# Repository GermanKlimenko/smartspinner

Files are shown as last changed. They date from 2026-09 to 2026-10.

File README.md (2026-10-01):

# Умный спиннер для трейдера

Проект **Смартлаба**. Выбранные визуальные направления: [«Пульс рынка»](public/assets/smartlab/market-full.png) и [«Биржевой сигнал»](public/assets/smartlab/signals-full.png). [Галерея на сайте](https://germanklimenko.github.io/smartspinner/#smartlab).

Это концептуальные изображения с демонстрационными котировками, не фотографии работающего прототипа. Свечной вариант не выбран и на сайте не размещён.

[Сайт проекта](https://germanklimenko.github.io/smartspinner/) · [Фото реального POV-вентилятора](public/assets/reference-fan/README.md)

## Текущий этап: неподвижный стенд B0.1

Документация для опытной ручной сборки подготовлена. **На железе не проверено.**
Цель конечного устройства: четыре луча, Ø100 мм, по 20 верхних и 12 торцевых RGB. Это целевые параметры, не характеристики испытанного образца.

- [Полный пакет стенда ZIP](bench/SmartSpinner_B01_DIY_Package.zip)
- [Инструкция PDF](bench/v0.1/output/pdf/SmartSpinner_B01_Bench.pdf)
- [Список покупок](bench/v0.1/shopping.md)
- [Исходники, схема соединений и прошивка](bench/v0.1/)
- [Результаты программных проверок](bench/v0.1/build/verification.txt)
- [Аудит электроники от 29.09.2026](audits/2026-09-29-electronics/README.md)

B0.1: UNO R3, 6 драйверов SM16306SJ, 32 выводных RGB LED, 96 каналов. Неподвижный опыт без аккумулятора и мотора. Не закреплять стенд на купленном голографическом вентиляторе.

## Старые версии сняты

**STOP FABRICATION. Прежние электрические файлы v0.4/v0.5 нельзя использовать для изготовления и подключения аккумулятора.**

Удалены из текущего каталога устаревшие версии v0.1/v0.2, электрические пакеты v0.4/v0.5 и прежние материалы с завышенной оценкой готовности. Они восстановимы из истории Git. Аудит относится к историческому коммиту [1635129](https://github.com/GermanKlimenko/smartspinner/tree/1635129707aff4e6b09a5e4b1feb32eedf14c7ca), поэтому его пути и контрольные суммы описывают именно тот снимок.

Сохранена параметрическая геометрия v0.3 как основа для переработки, а не согласованная с электроникой сборка. Визуализации — концептуальные рендеры, не фотографии работающего прототипа.

## Следующие шаги

1. Купить компоненты по списку B0.1 и собрать неподвижный стенд.
2. Проверить адресацию, токи, отключение, нагрев и оптические импульсы; заполнить протокол.
3. По результатам разработать новую компактную схему и PCB, согласовать с корпусом.
4. После ERC/DRC, DFM и проверки питания подготовить заказ 10 PCBA.

## Локальный запуск сайта

Node.js >= 22.13, pnpm. Команды: `pnpm install --frozen-lockfile`, `pnpm dev`, `pnpm build`.
Публикация — GitHub Pages через workflow в `.github/workflows/pages.yml`.

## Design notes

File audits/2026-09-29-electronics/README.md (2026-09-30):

# SmartSpinner — ревизия электроники с нуля

Примечание к публикации 30.09.2026: старые схемы и пакеты сняты из текущего каталога. Все пути и выводы ниже относятся к историческому коммиту [1635129](https://github.com/GermanKlimenko/smartspinner/tree/1635129707aff4e6b09a5e4b1feb32eedf14c7ca). Для повторного запуска аудита восстановите этот снимок в отдельной рабочей копии; не используйте его для изготовления.

Дата: 29 сентября 2026. Проверяемая база: Git `1635129`, схема v0.5, плата v0.4, механика v0.3. Это отчёт о проверке, **не исправленный производственный релиз**.

## Краткий вердикт

**STOP FABRICATION: по существующим файлам заказывать изготовление и монтаж нельзя. Подключать аккумулятор к собранной по ним плате нельзя.**

Проект содержит пригодную для обсуждения концепцию, но не согласованный комплект рабочего устройства. Обнаружены ошибки соединений питания, непригодные посадочные места, расхождение схемы с платой и платы с корпусом. Ранее данная оценка готовности была завышена: это не ситуация «разводчику осталось проверить несколько мелочей».

Сама идея четырёхлучевого POV-спиннера не опровергнута. Предварительно можно сохранить nRF52840/BLE и целевые 4 × 20 верхних + 4 × 12 торцевых RGB-пикселей. Но выбор LED, питание, фазовая синхронизация и размещение требуют новой проверки. Партнёрские картинки не являются доказательством достижимой чёткости.

### Что действительно проверено

- Прочитаны генераторы, исходные KiCad, BOM/CPL, файлы производства и механики.
- KiCad 10.0.6 заново экспортировал электрический netlist; заново выполнены ERC и DRC обеих плат.
- Соединения и посадочные места сопоставлены с документацией компонентов.
- Пересчитаны временной бюджет POV, пределы датчиков и сценарии энергопотребления.
- Контур PCB совмещён с действующими STEP-моделями, посчитаны пересечения твёрдых тел.

Не было изготовленного образца, осциллограмм, оптического теста, измерений температуры, тока, времени работы и радиосвязи. Проверка файлов не заменяет эти испытания. Дубликаты файлов с суффиксом « 2» не принимались за новую ревизию. Исходные проектные файлы не изменялись; контрольные суммы сохранены.

## 1. Подтверждённые блокирующие ошибки

### E01 · P0 · Генератор схемы перепутал физические выводы и сети

В `tools/generate_schematic_v0_5.py:88–92` локальные координаты выводов символа создаются с положительной осью Y вверх; в строке 158 метки соединений ставятся на листе без необходимого переворота Y. Поэтому порядок сетей на каждой стороне многовыводного символа развёрнут. Это не предположение по картинке: результат подтверждён экспортом KiCad.

| Компонент и физический вывод | Фактическая сеть в v0.5 | Требуемая функция |
|---|---|---|
| U5 MCP73831, 4 VDD | GND | Вход зарядки 5 В |
| U5, 2 VSS | CHG_5V | Земля |
| U5, 3 VBAT | CHG_STAT | Аккумулятор |
| U3 TPS61023, 3 VIN | GND | Аккумулятор |
| U3, 4 GND | VBAT | Земля |
| U3, 5 SW / 6 VOUT | 5V_RAW / BOOST_SW | BOOST_SW / 5V_RAW |
| U4 LDO, 1 IN / 2 GND | GND / VBAT | VBAT / GND |
| U4, 5 OUT | Не подключён | 3V3 |
| U1, 51 SWDIO / 53 SWDCLK | 3V3 / 3V3 | Интерфейс программирования |
| U1, 28 VDD / 30 VDDH | SWDCLK / SWDIO | Питание модуля |

Полный список: [schematic-connectivity.json](schematic-connectivity.json), исходный экспорт: [schematic.net.xml](schematic.net.xml). Та же ошибка затрагивает разъёмы и сигнальные цепи. Исправить одну надпись недостаточно: необходимо проверить соответствие каждого вывода каждой сети после регенерации.

Распиновки сверены с [Microchip MCP73831](https://ww1.microchip.com/downloads/en/DeviceDoc/20001984g.pdf), [TI TPS61023](https://www.ti.com/lit/ds/symlink/tps61023.pdf), [TI TPS7A20](https://www.ti.com/lit/ds/symlink/tps7a20.pdf) и [Raytac MDBT50Q](https://www.raytac.com/tw/download/index.php?index_id=24).

### E02 · P0 · «Нет ошибок ERC» здесь не означает исправную схему

В генераторе **все выводы объявлены `passive`**. ERC не получает нормального описания входов питания, выходов, открытых стоков и т. п. Перепутанное питание поэтому не выявляется привычными проверками типов выводов.

Новый прогон дал 89 предупреждений, 0 ошибок категории error. Но E01 остаётся реальной электрической ошибкой. Нужно заменить условные символы проверенными, назначить корректные типы выводов, обработать питание, NC и исключения, затем повторить ERC и ручную проверку netlist. Файл `.kicad_pro` с полноценными настройками проекта в проверяемом комплекте отсутствует.

### E03 · P0 · Неверно рассчитано напряжение повышающего преобразователя

Генератор задаёт R2 = 910 кОм и R3 = 100 кОм и утверждает, что опорное напряжение TPS61023 равно 0,5 В. По таблице electrical characteristics оно типично **0,595 В в PWM**, 0,601 В в PFM.

Расчёт задуманной цепи: `Vout = 0,595 × (1 + 910/100) = 6,0095 В`.

Это выше допустимого диапазона настройки выхода 5,5 В. Защита от перенапряжения вмешается; **расчёт не означает, что реально получится стабильный выход 6 В**. Даже после исправления E01 этот узел останется неправильным. Нужны новый делитель, расчёт допусков и проверка преобразователя с реальной нагрузкой. Источник: [TI TPS61023, таблица 6.5 и типовая схема](https://www.ti.com/lit/ds/symlink/tps61023.pdf).

### E04 · P0 · Посадочные места на PCB — условные заменители реальных корпусов

| Позиция | Площадок в v0.4 PCB | Выводов у указанного компонента |
|---|---:|---:|
| U1 MDBT50Q | 15 | 61 |
| U2, U9 74AHCT125 | 6 на корпус | 14 |
| U3 TPS61023 | 3 | 6 |
| U4 TPS7A20 | 3 | 5 |
| U5 MCP73831 | 3 | 5 |
| U7 BMI270 | 4 | 14 |
| U8 TPS22918 | 3 | 6 |

Это не просто отсутствие 3D-моделей. На эти площадки нельзя установить указанные детали с правильными соединениями. В v0.4 преобразователи изображены как трёхконтактные блоки; входы и выходы логических буферов не представлены как полноценная схема. Инвентаризация: [pcb-inventory.json](pcb-inventory.json).

### E05 · P0 · Схема, BOM и PCB не являются одним согласованным проектом

В схеме 40 символов; 31 без назначенного footprint, включая условные блоки цепочек LED. Все 128 светодиодов не развёрнуты в индивидуальные компоненты. В основной PCB 104 footprint; в одной торцевой 13, а таких торцевых плат предполагается четыре.

L1 и RPROG из BOM не найдены как компоненты основной PCB. Обратная связь и большая часть обвязки в PCB отсутствуют. Нумерация также изменилась: C1–C4 на плате v0.4 — четыре накопительных конденсатора лучей, в схеме v0.5 это другие конденсаторы зарядки и LDO. Нет основания использовать старые BOM/CPL для новой схемы.

Нужны единый проект, одна библиотека, уникальные позиционные обозначения и проверка `schematic ↔ PCB ↔ BOM ↔ CPL`. Экспорт Gerber из существующей геометрии этого не исправляет.

### E06 · P0 · Разводка не завершена, производственный пакет неполон

Свежий DRC основной платы: **68 неподключённых элементов**, плюс 50 прочих нарушений; торцевой: **4 неподключённых**, плюс 7 прочих. Это категории отчёта, не число уникальных цепей. См. [main-drc.json](main-drc.json), [tip-drc.json](tip-drc.json).

В опубликованном каталоге Gerber отсутствуют файлы паяльной маски и пасты для обеих сторон. См. [fabrication-files.json](fabrication-files.json). Наличие файлов меди и сверловки не делает пакет готовым для PCBA.

В основной PCB нет полигонов земли; внутренние слои заявлены, но полноценная структура возвратных токов не реализована. Графический прямоугольник RF keep-out не является запретной зоной для меди всех слоёв. Отверстия переходов 0,15 мм на основной и 0,10 мм на торцевой плате поставлены непосредственно в площадки LED. Это требует отдельного согласования технологии, заполнения/закрытия via-in-pad либо изменения разводки. Очень мягкие DRC-ограничения сами по себе не доказывают производимость.

### E07 · P0 · Корпус и плата физически несовместимы

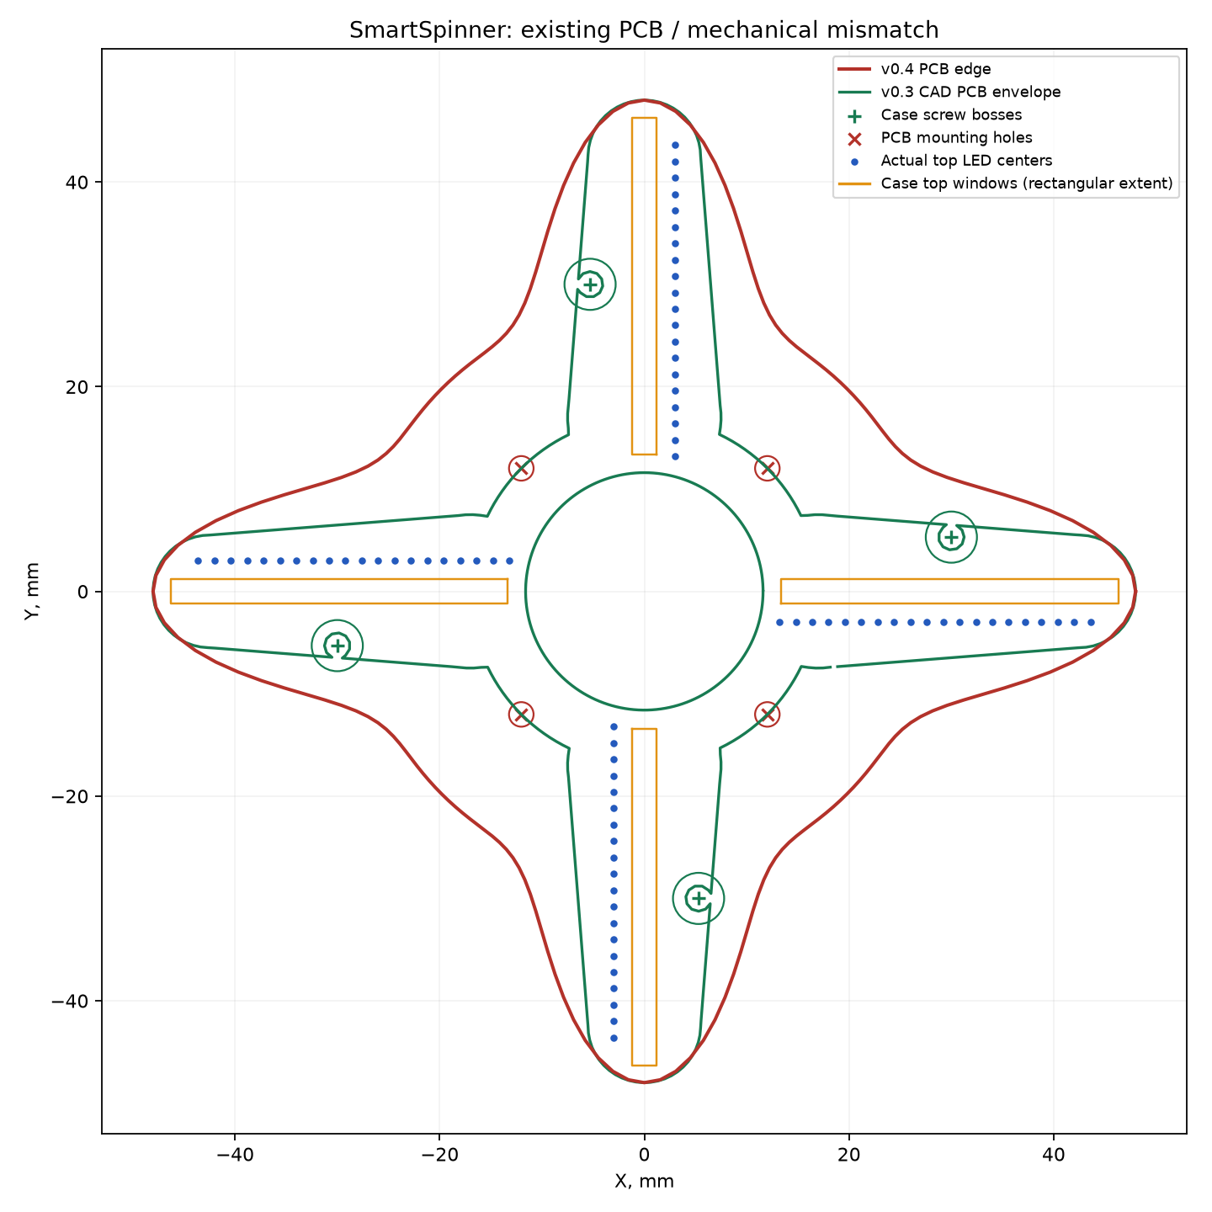
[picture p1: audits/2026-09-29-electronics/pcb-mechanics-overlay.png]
Совмещение актуальной платы и механики


Красный контур — PCB v0.4; зелёный — посадочный габарит PCB в механике v0.3; синие точки — LED; оранжевые полосы — окна.

- Отверстия PCB стоят около радиуса 17 мм по диагоналям. В корпусе крепёж расположен около точек `(30; 5,3)` мм и их поворотов на 90°. Они не совпадают.
- Лучи PCB существенно шире полостей корпуса. При положении платы Z = 6,5…7,5 мм объём пересечения PCB с нижней частью корпуса составляет около **625 мм³**.
- Даже предусмотренный в v0.3 STEP-габарит платы пересекается с нижней частью корпуса: около **216 мм³**. Поэтому нельзя считать и прежнюю механику полностью проверенной.
- Ряд верхних LED смещён поперёк луча на 3 мм, тогда как полуширина окна 1,2 мм. Ряд не попадает в предусмотренное окно.
- Первый LED начинается с 13,2 мм вместо 14,8 мм; шаг торцевых LED 1,10 мм против 1,05 мм в механике. На 12 позициях разница длины ряда 0,55 мм.
- Проверяемая механика имеет толщину 16 мм, а не первоначальные 12–14 мм. Между верхними LED и рассеивателем есть большой зазор; резкость и паразитная засветка не проверены.

Расчёт выполнен на настоящих STEP-телах, не на иллюстрации. Преобразование координат и допущения сохранены в [mechanical-comparison.json](mechanical-comparison.json). Нужны общие параметры механики и платы, компонентные 3D-модели, проверка всех зазоров и сборки.

## 2. Компоненты, питание и безопасный запуск

### E08 · P0 · MPN датчика Hall не соответствует выбранному корпусу

Указанный **DRV5033AJQLPGM** — вариант TO-92/LPG; в схеме ему назначен SOT-23, а в BOM встречается другой тип корпуса. Более того, назначение выводов 2/3 у LPG и SOT-23/DBZ различается. Нельзя просто заменить рисунок footprint без проверки MPN и pin map. [TI: именно DRV5033AJQLPGM](https://www.ti.com/product/es-mx/DRV5033/part-details/DRV5033AJQLPGM), [распиновки](https://www.ti.com/lit/ds/symlink/drv5033.pdf).

### E09 · P0 · Распиновки LED не подтверждены для заказываемой модификации

На PCB оба типа LED используют `1=VDD, 2=DOUT, 3=GND, 4=DIN`. Документ OPSCO для EC10 показывает `1=GND, 2=DIN, 3=VDD, 4=DOUT`; документ Normand для EC15 — `1=DIN, 2=VDD, 3=DOUT, 4=GND`.

Нумерация и ориентация должны быть согласованы с **конкретным производителем и ревизией**. Для EC10 поворот корпуса может объяснять часть пространственного соответствия, но не доказывает правильность нумерации, CPL и сборочной ориентации. Документ EC15 от Normand не является подтверждением всех вариантов OPSCO. До выбора закупаемой позиции обе посадки остаются неподтверждёнными. Нужны land pattern, pin-1, ориентация ленты и контрольный монтаж.

Источники: [OPSCO EC10 REV.01](https://cdn-shop.adafruit.com/product-files/5849/SK6805-EC10-000_REV.01_EN.pdf), [Normand EC15 REV.05](https://www.normandled.com/upload/202003/SK6805-EC15%20LED%20Datasheet.pdf).

### E10 · P1 · Зарядка и совместимость уровней

Даже по задуманным, ещё не перепутанным соединениям STAT у MCP73831 напрямую идёт в GPIO nRF. Этот выход может выдавать высокий уровень от входного питания зарядки, то есть около 5 В. Для 3,3-вольтового GPIO нужен согласователь либо подходящий вариант выхода с открытым стоком и подтяжкой к 3,3 В.

RPROG = 10 кОм задаёт около 100 мА; это не 150 мА, фигурировавшие в BOM. Для условных 500 мА·ч одна только идеальная зарядка током 100 мА заняла бы 5 часов, реальная с фазой CV — дольше. Отдельного power-path нет: потребление устройства от батарейного узла может нарушать определение окончания зарядки. Следует аппаратно исключить работу LED на зарядке либо спроектировать корректное разделение питания. [Microchip MCP73831/2](https://ww1.microchip.com/downloads/en/DeviceDoc/20001984g.pdf).

Зарядник не заменяет защиту аккумулятора от КЗ/переразряда. Нужны точная модель пакета, допустимые токи, защитная плата и температурные условия зарядки. Две симметричные ячейки нельзя считать согласованным 1S2P-пакетом без определения их соединения, одинаковости и защиты. Полости в корпусе не доказывают существование подходящего аккумулятора на 500 мА·ч.

### E11 · P1 · Питание требует полного пересчёта и проверки переходных процессов

- «3,7 A» у TPS61023 — предел тока ключа, а не гарантированные 3,7 A на выходе 5 В. Нужен расчёт при минимальном напряжении батареи, с потерями, нагревом и насыщением дросселя.
- [TPS22918](https://www.ti.com/lit/ds/symlink/tps22918.pdf) рассчитан на ток до 2 A при оговорённых условиях, но не является программируемым ограничителем тока. Один только предел яркости в прошивке не защищает от её сбоя или всех переходных нагрузок.
- На LED_EN нет гарантированного выключенного состояния внешним резистором. Нужно определить запуск, сброс MCU, отключение и последовательность шин. ON нельзя оставлять плавающим. Неподключённый QOD сам по себе допустим и не является доказанной ошибкой.
- 3,3-вольтовый LDO от Li-ion перестаёт стабилизировать 3,3 В в нижней части разряда. Это не обязательно останавливает MCU, но требует проверки минимального питания всех узлов и порога отключения. [TPS7A20](https://www.ti.com/lit/ds/symlink/tps7a20.pdf).
- Недостаточно локальной развязки у контроллера, буферов, Hall и цепей LED. Требуется расчёт эффективной ёмкости с DC-bias, токов по лучам, провалов питания, возвратных путей и помех BLE.
- Режим «LED показывают чёрный» и режим «питание LED выключено» имеют разное потребление. Для ожидания нужно физическое отключение световой части.

### E12 · P1 · Буферы, GPIO, программирование и RF

74AHCT125 — подходящий класс согласования 3,3 → 5 В при правильном подключении: AHCT питается от 4,5–5,5 В и имеет TTL-порог входа. В старой PCB буферы сидят на 3V3 и не реализуют нужное преобразование. Входы актуального Nexperia имеют overvoltage tolerance; поэтому утверждать неизбежную обратную подпитку именно через их входную защиту нельзя. Всё равно необходимо проверить поведение выключенных шин и выходов. [Nexperia 74AHC/AHCT125](https://assets.nexperia.com/documents/data-sheet/74AHC_AHCT125.pdf).

Задуманное назначение P0.03/P0.09/P0.10 под высокочастотные LED-данные не учитывает RF-рекомендации модуля: эти выводы имеют ограничения при активном радио. Нужен новый GPIO-план, проверка NFC-конфигурации, режима питания модуля, неиспользуемых выводов и физического keep-out антенны. [Raytac MDBT50Q](https://www.raytac.com/tw/download/index.php?index_id=24).

SWD-разъём не согласован: пять выводов в схеме, четыре площадки на PCB, шестиконтактный интерфейс в BOM. Для варианта TC2030-CTX контакт 3 — reset, 4 — clock; задуманная схема меняет их местами. Нужно выбрать конкретный кабель и посадку, обеспечить доступ при сборке. [Tag-Connect TC2030-CTX](https://www.tag-connect.com/product/tc2030-ctx-etm).

## 3. Сможет ли это показывать картинку

### E13 · P1 · Четыре луча не устраняют ограничения LED

Проверяемая гипотеза: восемь независимых цепочек — четыре по 20 LED сверху и четыре по 12 LED на торце, передача 800 кбит/с, 24 бита на RGB, reset более 80 мкс. Нижние границы времени обновления — около 680 и 440 мкс соответственно. Это оптимистичный предел без затрат прошивки, а не измеренная производительность.

| Скорость, об/мин | Проходов 4 лучей в секунду | Обновлений за оборот одной верхней цепочки, не более | Торцевой, не более |
|---:|---:|---:|---:|
| 300 | 20 | 294 | 454 |
| 600 | 40 | 147 | 227 |
| 900 | 60 | 98 | 151 |
| 1200 | 80 | 73 | 113 |

При 900 об/мин за 680 мкс точка на радиусе 50 мм перемещается примерно на 3,20 мм. У реального крайнего верхнего LED радиус меньше, поэтому линейное перемещение немного меньше. Это ограничивает угловую детализацию. Четыре луча увеличивают повторяемость изображения; нельзя одновременно считать их безусловным четырёхкратным приростом и частоты, и углового разрешения.

Отдельный предел — внутренний PWM светодиода. В проверенных документах встречаются 1,2 кГц для EC15 и 4 кГц для EC10; другие ревизии могут отличаться. PWM не синхронизирован с вращением, поэтому нужно проверить оптическую задержку, полосы и разрывы на малой яркости. Нельзя выводить качество изображения только из скорости передачи данных.

**Вывод:** выбранные LED не доказаны как подходящие для обещанной чёткой графики. Это не доказательство невозможности POV. До окончательной разводки нужен оптический стенд с реальными закупаемыми LED и измерением света фотодиодом. Если результата нет — переход на проверенное быстрое тактируемое решение или RGB-драйверы с управляемыми latch/OE. Конкретный заменяющий компонент пока не выбран; его геометрия и токи тоже потребуют расчёта.

20 LED по лучу дают 20 радиальных отсчётов, не квадрат 20 × 20. Центральная область остаётся без изображения из-за подшипника и пальцев. Полярный рендеринг должен учитывать реальные координаты каждого LED, а не только радиус.

### E14 · P1 · nRF52840 предварительно пригоден, доказательной прошивки нет

У nRF52840 есть четыре PWM-блока по четыре канала с EasyDMA. Поэтому восемь параллельных потоков технически возможны; отдельный GPIO на каждый из 128 LED не нужен. Но требуется реализовать и измерить генерацию восьми потоков, фазовую синхронизацию и работу одновременно с BLE. В проверяемом проекте рабочая прошивка этого не обнаружена. [Nordic: возможности nRF52840](https://docs.nordicsemi.com/r/bundle/ps_nrf52840/page/keyfeatures_html5.html).

Нужны обработчик Hall с аппаратными timestamp, планировщик угла, корректировка изменения периода, буферы полярного изображения, watchdog, контроль батареи и аппаратно безопасное гашение при остановке/сбросе. Bluetooth должен передавать содержимое, не задавать точные моменты включения LED.

### E15 · P1 · BMI270 не подходит для заявленной роли измерителя скорости вращения

Максимальный диапазон гироскопа ±2000°/с соответствует около **333 об/мин**. При 600 об/мин уже 3600°/с, при 900 — 5400°/с. Он будет насыщаться, поэтому не может гарантированно компенсировать скорость и фазу в этом диапазоне.

При радиусе 14 мм и 1200 об/мин центростремительное ускорение около 22,5g, выше диапазона акселерометра ±16g. IMU можно оставить для других задач после пересмотра роли, но не обещать на его основе стабилизацию изображения. [Bosch BMI270](https://www.bosch-sensortec.com/en/products/motion-sensors/imus/bmi270).

### E16 · P1 · Hall, магнит и дрожание руки

В механике **есть** карман магнита в неподвижной относительно пальцев крышке — неверно было бы объявлять магнит полностью забытым. Но модель, ориентация и поле магнита не заданы в BOM; положение Hall на PCB не совпадает с механической разметкой. Работу рядом со стальным подшипником, допуски зазора и стабильность импульса никто не измерял.

Одна метка за оборот даёт период и индекс, но не непрерывный угол между импульсами. Она не измеряет направление без дополнительных предположений. Если крышка поворачивается в пальцах, вместе с ней меняется опорное направление картинки. Дрожание оси также не исправляется одной меткой.

Для первой версии рационально разделить: синхронизацию относительно крышки, оценку изменения скорости и отдельно устойчивость изображения в руке. Жёсткий стенд нужен для измерений и отладки; из этого не следует, что устройство сможет работать только на подставке. Финальное доказательство удобства и чёткости — тест в руке, а не рендер.

## 4. Энергия: новый расчёт вместо обещания автономности

128 RGB-пикселей — это до 384 цветовых каналов. При условных 5 мА на канал полный белый требует **1,92 A при 5 В только на свечение**, ещё до собственного потребления микросхем LED. «5 мА на пиксель» не равно «5 мА на каждый цвет».

Следующая таблица — **сценарная чувствительность, не спецификация батареи и не прогноз измеренной автономности**. Приняты условные 0,5 мА собственного тока каждого LED, 5 мА на цветовой канал, КПД boost 85%, батарея 3,7 В / 500 мА·ч, используемая ёмкость 85%, прочая электроника 15 мА от батареи. Токи конкретных ревизий LED и реальная ёмкость подходящего пакета пока не подтверждены.

| Средняя загрузка цветовых каналов | Ток LED по 5 В | Ток батареи | Расчётное время |
|---:|---:|---:|---:|
| 0%, питание LED включено | 64 мА | 117 мА | 218 мин |
| 10% | 256 мА | 422 мА | 60 мин |
| 25% | 544 мА | 880 мА | 29 мин |
| 35% | 736 мА | 1185 мА | 22 мин |
| 100%, полный белый | 1984 мА | 3169 мА | 8 мин — математически, режим не разрешён |

«Загрузка» учитывает одновременно долю светящихся точек, яркость и количество активных цветов. Это не просто положение ползунка яркости. Редкий зелёный текст и сплошной белый диск дают совершенно разные результаты. При низком напряжении батареи входной ток ещё выше. Возможности маленького аккумулятора, защита и нагрев могут исключить режим задолго до расчётного исчерпания ёмкости.

Ограничение яркости снижает средний ток, но не обязательно амплитуду импульсов PWM. Проверять нужно среднюю и пиковую нагрузку, ёмкости и провалы питания. Пока корректный ответ об автономности: **не установлена**. Все формулы и допущения: [calculations.json](calculations.json).

## 5. Предлагаемая архитектура следующей ревизии

Сохранить целевой форм-фактор и BLE как требования, но не копировать нынешнюю разводку. Рекомендуемый порядок решений:

1. **Оптика до финальной PCB.** Один луч 20 LED и один торец 12 LED, настоящий световой тест в диапазоне 300–1200 об/мин. Диапазон — испытательный, а не утверждение о типичной скорости в руках. Выбрать допустимое качество текста, мерцание, яркость и минимальные рабочие обороты.
2. **Согласовать аккумулятор и питание.** Выбрать физически существующий защищённый пакет, токовый бюджет, зарядку, режим на доке и аппаратное выключение LED. После этого выбирать преобразователь и ограничение нагрузки.
3. **Собрать полную принципиальную схему заново.** Реальные символы, все светодиоды и обвязка, разъёмы, измерительные точки, программирование, режимы включения/выключения. Добавить автоматические проверки критических pin-to-net соединений, чтобы ошибка генератора не повторилась.
4. **Совместно переработать размещение и корпус.** Единый DXF/параметры, допустимые зоны компонентов, световые окна, высоты, антенна, магниты, батарея, крепёж и балансировка по реальным массам. Четыре одинаковых луча сами по себе баланс не гарантируют. Торцевые платы должны фиксироваться корпусом; пайка не должна воспринимать удар раскрутки.
5. **Развести согласованную плату.** Проверенные footprints из документации поставщиков, питание/земля/RF, технологические ограничения выбранного производства. Устранить все неподключения, разрешить каждое исключение ERC/DRC, сравнить netlist.
6. **Первый экземпляр и испытания.** Лабораторный источник с ограничением тока до аккумулятора; проверка шин, зарядки, запуска, LED, Hall, BLE и температуры. Затем безопасный тест вращения в защитном ограждении и тест в руке. Лишь после этого — партия 10 устройств.

### Критерии готовности к заказу

- Одна версия KiCad: `.kicad_pro`, `.kicad_sch`, `.kicad_pcb`, локальные библиотеки и 3D-модели.
- PDF полной схемы, BOM с точными MPN и допустимыми заменами, CPL, сборочные чертежи с pin-1 и ориентацией.
- Gerber меди, маски, пасты, шелкографии и контура; сверловка, стек слоёв, требования via-in-pad и панелизации.
- Разъёмы и четыре торцевых модуля согласованы по числу, нумерации, стороне и монтажу.
- ERC/DRC и сверка схемы с платой без необъяснённых нарушений; независимая проверка питания и распиновок; DFM от изготовителя.
- Расчёты питания, токов, нагрева и световых таймингов; согласованная батарея и механика.
- Прошивка для проверки, инструкция первого включения и критерии приёмки.

Отдельный критерий после изготовления: реальная чёткость POV, автономность, нагрев, безопасность батареи и прочность подтверждены измерениями. Даже идеальные файлы не дают этого доказательства заранее.

## 6. Что это означает для переговоров с разработчиком

Нужен заказ **на разработку и проверку электроники прототипа**, а не только на трассировку готовой схемы. Изготовитель PCBA может выпустить и собрать платы по согласованным файлам, но не обязан бесплатно доводить принцип работы и исправлять архитектуру.

Техническое возражение, что имеющейся схемы недостаточно, подтверждается аудитом. При этом аудит не проверяет коммерческую оценку Азата и не позволяет обещать конкретное число часов экономии. Будущему исполнителю стоит передать этот отчёт и исходники как материал для ревизии, прямо исключив использование старых Gerber для заказа.

## 7. Воспроизводимость и границы изменений

Добавлены только файлы аудита и два проверочных скрипта; старые схема, PCB, CAD, сайт и производственные архивы не исправлялись и не публиковались. Письма и сообщения никому не отправлялись.

Запуск из корня репозитория:

```bash
python3 tools/audit_electronics.py
.venv/bin/python tools/audit_electromechanical.py
```

Первый скрипт использует установленный KiCad CLI 10.0.6; второй — CadQuery и Matplotlib из локальной `.venv`. Путь KiCad задан явно и на другом компьютере требует настройки. Скрипты читают исходники и записывают отчёты в эту папку. Существующие проектные генераторы в ходе аудита не запускались.

Доказательства: [команды и коды возврата](commands.json), [контрольные суммы исходников](source-hashes.json), [ERC](erc.txt), [DRC основной платы](main-drc.json), [DRC торцевой платы](tip-drc.json), [инвентаризация PCB](pcb-inventory.json), [расчёты](calculations.json), [геометрическое сравнение](mechanical-comparison.json).

Это широкий аудит доступных файлов и ключевых проектных допущений, а не сертификация и не гарантия отсутствия других ошибок. Точные компоненты, исправленная схема, полная разводка и измерения первого экземпляра ещё предстоят.

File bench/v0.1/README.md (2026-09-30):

# SmartSpinner B0.1 - настольный стенд

Дата: 29.09.2026. Статус: **документация для опытной ручной сборки; на железе не проверено**.

Это отдельная ветвь исследований, а не новая производственная версия спиннера. Старые v0.3-v0.5 не используются как проверенные схемы. Ничего из этого комплекта нельзя закреплять на работающем голографическом вентиляторе.

Начать с `manual.md` или `output/pdf/SmartSpinner_B01_Bench.pdf`. Полная таблица проводов: `wiring.html`; машиночитаемые соединения: `wiring.json`. Схема питания и управления: `schematic.svg`. Детальный список покупок: `shopping.md` и разделы 2-3 инструкции. Прошивка: `firmware/spinner_bench/`.

## Результат этапа

Один неподвижный эквивалент луча: 20 верхних + 12 торцевых RGB, 6 драйверов SM16306SJ, около 5 мА на цветовой канал. Все 32 LED лежат на столе. Arduino UNO R3 - временный генератор тестовых сигналов, не замена nRF52 в конечном устройстве. Выводные LED диаметром 5 мм выбраны ради удобства пайки, а не для установки в корпус Ø100 мм.

Проверяем адресацию 96 каналов, ток, отключение, обмен и оптические импульсы. Не проверяем читаемость POV, ресурс аккумулятора, BLE, балансировку, Hall-синхронизацию, четыре луча одновременно и безопасность вращения. Для них нужны следующие прототипы.

## Сборка программной части

Arduino IDE: установить Arduino AVR Boards 1.8.8, выбрать **Arduino Uno**, открыть `.ino`, загрузить только при отключённом LED-питании и S1=OFF. Монитор порта: 115200, окончание строки Newline. **Uno R4, Nano ESP32 и UNO R3 3.3V не подходят под эту прошивку**.

CLI из каталога этого пакета:

```sh
arduino-cli compile --fqbn arduino:avr:uno --output-dir build/uno firmware/spinner_bench
c++ -std=c++11 -Wall -Wextra -Werror tests/test_core.cpp -o /tmp/spinner_bench_test
/tmp/spinner_bench_test
python3 tools/verify_wiring.py
```

`build/verification.txt` фиксирует выполненные программные проверки, не физические испытания. `test_record.md` заполняется после сборки; сейчас все измерения **НЕ ПРОВЕДЕНЫ**.

## Как воспроизвести документы

Python 3 с reportlab, pypdf: `python3 tools/build_docs.py`. Генератор создаёт PDF, SVG, HTML и JSON; не изменяет старый проект. `manual.md` - редактируемый русский оригинал. Официальные datasheet не перепакованы в архив: ссылки даны в инструкции. Сверять ориентацию корпусов с ними обязательно.

## Что не заказывать сейчас

Не покупать аккумуляторы, зарядные платы, мотор, корпус, готовые производственные платы спиннера и 128 миниатюрных RGB. Не заказывать Gerber из старого проекта. Для стенда заказ PCB не нужен: макетные платы и переходники. Если нет точного SM16306SJ или совместимого QSOP24-переходника, остановить закупку этих позиций, прислать карточку аналога для проверки; не подменять автоматически.

Пакет подготовлен локально. Публикация и покупки не выполнены.

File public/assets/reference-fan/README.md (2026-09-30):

# Реальные фотографии LED-вентилятора

Снимки предоставлены владельцем проекта Германом, 29.09.2026; опубликованы с его разрешения. Это купленный POV-вентилятор, а не изготовленный SmartSpinner.

- [LED с миллиметровой линейкой](led-ruler.jpg)
- [Обратная сторона: маркировка SM16306SJ](driver-sm16306sj.jpg)
- [Крупный план LED-линейки](led-closeup.jpg)

Точный артикул и корпус светодиода по фото не установлен. Показатели продавца не считаются измеренными характеристиками. Эти фото помогают выбирать эксперимент, но не доказывают работоспособность нашей схемы.

При подготовке нормализирована ориентация и удалены EXIF/GPS-метаданные. Содержимое устройства не ретушировалось. Оригиналы остались у владельца. Купленный вентилятор не предназначен для крепления самодельного стенда на вращающиеся лопасти.

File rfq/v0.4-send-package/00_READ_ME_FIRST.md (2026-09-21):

# SmartSpinner v0.4 - supplier RFQ package

## Purpose

This package is ready to send to a PCB engineering and turnkey PCBA supplier for:

1. review and completion of the supplied KiCad layout;
2. DFM, footprint and sourcing review;
3. a quotation for one first article followed by 10 complete electronic sets.

The current design is an engineering release and is **not approved for fabrication**. The supplier must return updated editable KiCad sources and a zero-error DRC report for customer approval before manufacturing.

## One complete electronic set

- 1 four-arm main PCB with 80 top RGB pixels;
- 4 identical vertical tip PCBs with 12 RGB pixels each;
- 128 RGB pixels total;
- nRF52840 BLE, BMI270 IMU and DRV5033 Hall sensor;
- protected 1S LiPo input, 3.3 V logic and switched 5 V LED rail;
- batteries and 3D-printed enclosure excluded from the PCBA shipment.

## Files to review first

1. `SmartSpinner_v0_4_RFQ_Brief_EN.pdf`
2. `01_RFQ_EMAIL_EN.txt`
3. `01_RFQ_EMAIL_RU.txt`
4. `02_SUPPLIER_RESPONSE_TEMPLATE.csv`
5. `03_OPEN_ITEMS_AND_ACCEPTANCE.md`
6. `SmartSpinner_v0_4_electronics_ERC.zip`
7. `ticker_spinner_v0_3_complete_package.zip`

## Public references

- Project website: https://germanklimenko.github.io/smartspinner/
- Repository: https://github.com/GermanKlimenko/smartspinner

## Owner

German Klimenko

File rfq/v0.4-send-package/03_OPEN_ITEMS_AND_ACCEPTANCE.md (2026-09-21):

# Open items and acceptance criteria

## Known open items

- Main PCB DRC currently reports 68 unconnected items.
- Tip PCB DRC currently reports 4 unconnected items.
- Exact manufacturer land patterns and pin-1 orientation require verification.
- TPS61023 boost, MCP73831 charging and local decoupling networks require final datasheet review.
- Raytac MDBT50Q-1MV2 antenna keep-out must be checked on every copper layer and against the enclosure.
- Silkscreen and cosmetic DRC warnings require review.
- BOM sourcing identifiers and acceptable alternates require supplier confirmation.

## Engineering acceptance before fabrication

- Editable KiCad project returned to the customer.
- Zero copper errors and zero unconnected items in DRC for both board types.
- ERC completed with every waiver documented.
- Exact footprints checked against selected MPN datasheets.
- Final four-layer stack-up and impedance assumptions documented.
- Antenna keep-out and RF placement reviewed.
- Power-path, charging, boost, switching and decoupling networks reviewed.
- Final Gerber, drill, IPC-356 or equivalent netlist, BOM, CPL and assembly drawings generated from the approved sources.
- Supplier DFM report completed and all findings resolved or accepted in writing.

## First-article acceptance

- Only one complete electronic set is assembled initially.
- Visual inspection and AOI completed.
- No short circuit on battery, 3.3 V or 5 V rails.
- Charging and protected battery operation verified with a laboratory supply before connecting a LiPo cell.
- MCU programming and BLE advertisement verified.
- Hall and IMU communication verified.
- All eight LED data streams verified at limited brightness.
- Current consumption and thermal behavior recorded.
- Mechanical fit and static balance checked before powered rotation.

No remaining units may be assembled until the customer approves first-article results.

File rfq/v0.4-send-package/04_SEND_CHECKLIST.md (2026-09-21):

# Send checklist

- Replace `[COMPANY]` in the email subject and greeting.
- Attach `SmartSpinner_v0_4_RFQ_Send_Package.zip` or provide its download link.
- Ask the supplier to acknowledge the `NOT FOR FABRICATION` status.
- Request separate prices for engineering and manufacturing.
- Request 5-set, 10-set and 25-set quantity breaks.
- Request one first article before the remaining build.
- Require updated editable KiCad sources as a contractual deliverable.
- Require zero-error DRC and final DFM reports before approval.
- Exclude LiPo batteries from the shipment.
- Do not authorize fabrication until technical questions and revised files have been reviewed.

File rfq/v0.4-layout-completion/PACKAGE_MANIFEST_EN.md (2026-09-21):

# SmartSpinner v0.4 - PCB layout completion and PCBA RFQ

## Purpose

This package is for engineering review, completion of the PCB layout, DFM, sourcing and a budgetary turnkey-PCBA quotation. It is **not authorized for fabrication in its current state**.

## Quantity

- 10 complete electronic sets: 10 main four-arm PCBs plus 40 identical vertical tip PCBs.
- Please also quote 5-set and 25-set alternatives.
- Build one first article before releasing the remainder.

## Included

- KiCad main and tip board sources with routed pixel chains.
- Review-only Gerber and Excellon outputs.
- BOM with preferred MPNs and sourcing identifiers.
- KiCad position/CPL files.
- Four-page electrical architecture PDF and two-page fabrication drawing.
- Net summary, power budget, bring-up procedure and machine-readable DRC status.
- Mechanical v0.3 STEP/STL/DXF package and enclosure drawings.

## Work requested from supplier

1. Close all open connections listed in the KiCad DRC reports.
2. Replace/verify embedded custom footprints against exact manufacturer land patterns and pin-1 orientation.
3. Complete the TPS61023 boost, MCP73831 charge and decoupling networks from datasheets.
4. Review the Raytac antenna keep-out on all copper layers and against the enclosure.
5. Run DFM and return updated editable KiCad sources for approval.
6. After approval, regenerate fabrication Gerbers, assemble one first article and perform AOI plus the supplied electrical test sequence.

## Architecture

- Four-arm main PCB, up to 96 mm envelope, 1.0 mm four-layer target.
- 80 top SK6805-EC15 pixels in four independent 20-pixel chains.
- Four 0.6 mm tip boards, each with 12 SK6805-EC10 pixels on a separate data chain.
- Eight LED streams total through two 74AHCT125 devices.
- Raytac MDBT50Q-1MV2 (nRF52840), DRV5033 Hall sensor and BMI270 IMU.
- Protected 1S LiPo domain, 3.3 V logic and switched 5 V LED rail.
- Batteries excluded from the shipment.

## Public references

- Website: https://germanklimenko.github.io/smartspinner/
- Repository: https://github.com/GermanKlimenko/smartspinner
- Electronics package: https://germanklimenko.github.io/smartspinner/project-files/SmartSpinner_v0_4_electronics_ERC.zip
- Mechanical package: https://germanklimenko.github.io/smartspinner/project-files/ticker_spinner_v0_3_complete_package.zip

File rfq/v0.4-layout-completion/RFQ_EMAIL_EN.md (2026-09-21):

Subject: PCB layout completion + turnkey PCBA RFQ - SmartSpinner v0.4, 10 sets

Hello [COMPANY] Engineering Team,

My name is German Klimenko. I am developing SmartSpinner, a 100 mm four-arm persistence-of-vision display with Bluetooth connectivity.

I would like a quotation for two stages:

1. engineering completion of the supplied KiCad design, including schematic/detail review, closing all open DRC connections, exact-footprint verification, power-stage completion, RF keep-out review and DFM;
2. manufacture and turnkey assembly of 10 complete electronic sets after I approve the updated design.

Each set contains one four-arm main PCB with 80 top RGB pixels and four vertical tip PCBs with 12 RGB pixels each. The design uses eight independent LED data streams, an nRF52840 BLE module, BMI270 IMU, Hall index sensor, protected 1S LiPo input, 3.3 V logic and a switched 5 V LED rail.

The v0.4 package includes KiCad PCB sources, review Gerbers/drill, BOM, CPL, electrical architecture, fabrication drawing, power budget, DRC reports and a first-article test procedure. The current Gerbers are **not approved for fabrication**: the included release-status file records open central/interface connections that your layout engineer must close before DFM sign-off.

Project references:

- Website: https://germanklimenko.github.io/smartspinner/
- Repository: https://github.com/GermanKlimenko/smartspinner
- Electronics package: https://germanklimenko.github.io/smartspinner/project-files/SmartSpinner_v0_4_electronics_ERC.zip
- Mechanical package: https://germanklimenko.github.io/smartspinner/project-files/ticker_spinner_v0_3_complete_package.zip

Please quote separately:

- engineering/layout completion and number of included revision rounds;
- PCB fabrication for 10 main boards and 40 tip boards;
- components and alternates;
- SMT assembly, stencil/tooling and AOI;
- one first article plus the remaining production quantity;
- optional nRF52 programming and functional testing;
- shipping to Moscow, Russia, with no LiPo batteries included.

Please also confirm whether your engineers will return the updated editable KiCad project and a zero-error DRC report before fabrication.

Best regards,
German Klimenko
SmartSpinner project
https://germanklimenko.github.io/smartspinner/

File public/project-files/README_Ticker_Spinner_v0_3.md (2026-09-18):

# Ticker Spinner v0.3 - 12-pixel cylindrical ticker

Параметрический механический прототип четырёхлучевого POV-спиннера.

## Что входит

- `ticker_spinner_v0_3_bottom.stl/.step` — нижняя ванна, посадка 608, карманы аккумуляторов, стойки M2.
- `ticker_spinner_v0_3_top.stl/.step` — съёмная крышка, верхние и торцевые световые окна.
- `ticker_spinner_v0_3_diffusers.stl/.step` — четыре соединённых рассеивателя верхних LED.
- `ticker_spinner_v0_3_finger_cap_top.stl/.step` и `..._bottom.stl/.step` — неподвижные накладки для удержания за внутреннее кольцо 608.
- `ticker_spinner_v0_3_assembly.step` — механическая сборка с PCB-envelope.
- `ticker_spinner_v0_3_pcb_outline.dxf` — контур, NPTH, LED и функциональные зоны по слоям.
- `ticker_spinner_v0_3_tip_led_board.dxf` — вертикальная плата 12 торцевых LED; требуется 4 шт.
- `ticker_spinner_v0_3_engineering_drawing.pdf` и PNG — размерная справка.
- `ticker_spinner_v0_3_validation.json` — автоматическая проверка STL.

Электрическая схема, KiCad-разводка, BOM и pin-map в этот пакет намеренно не включены: сначала нужно утвердить конкретные корпуса LED, nRF52, IMU, зарядник и аккумулятор.

## Зафиксированная геометрия

- Габарит: **Ø100 × 16 мм**.
- Подшипник: **608 (22 × 7 × 8 мм)**; печатная посадка Ø21.85 мм.
- PCB: ориентировочно 1,0 мм, внешний габарит до Ø96 мм, отверстие центра Ø23.2 мм.
- Верх: 20 LED на луч, шаг 1.60 мм, 80 всего; рассчитано на корпус класса 1,3 × 1,3 мм.
- Торец: вертикальная колонка 12 адресных RGB LED на луч, 48 всего; четыре сменные tip-board 7 × 13,6 × 0,6 мм.
- Крепёж: 4 × M2, симметрия 90°.
- Универсальные карманы: 4 × 20 × 11.5 × 3.2 мм; аккумуляторы ставятся противоположной согласованной парой.

## Важные инженерные оговорки

Это v0.3 механики и **основа для разводки**, а не готовая электрическая схема. Для торцевой строки принят адресный WS2812B-0909 либо совместимый корпус 0,9 × 0,9 мм; перед заказом нужно проверить фактический footprint выбранного производителя. К единой основной PCB добавлены четыре одинаковые ремонтопригодные торцевые платы, механически удерживаемые направляющими корпуса. Перед финальной PCB нужно утвердить nRF52-модуль, Hall, IMU, зарядник и способ связи/зарядки. Для раннего прототипа безопаснее ставить один аккумулятор и равную балластную массу напротив; для большей ёмкости — только согласованную защищённую пару в противоположных карманах.

Перед печатью корпуса напечатайте маленький coupon с отверстиями Ø21.70 / 21.85 / 22.00 / 22.15 мм и выберите посадку под конкретный принтер и материал. Для первой печати: PETG, слой 0,2 мм, 4 периметра, 30–40% infill. Крышка и низ печатаются внешней плоской стороной на столе; рассеиватель — прозрачным/молочным PETG либо отливается прозрачной смолой.

Балансировка обязательна после монтажа: предусмотрены четыре равных зоны trim-weight в DXF. Сначала статическая балансировка, затем динамическая на ограниченных оборотах в защитном кожухе.

## Перегенерация

Главные параметры находятся в словаре `P` файла `generate_ticker_spinner_v0_3.py`. После изменения запустите его в Python-окружении с зависимостями из `requirements_ticker_spinner_v0_3.txt`; все форматы пересобираются из одной геометрии.

## Результат проверки

```json
{
  "ticker_spinner_v0_3_bottom.stl": {
    "watertight": true,
    "body_count": 1,
    "bounds_mm": [
      [
        -49.999,
        -49.999,
        0.0
      ],
      [
        49.999,
        49.999,
        8.0
      ]
    ],
    "extents_mm": [
      99.998,
      99.998,
      8.0
    ],
    "volume_mm3": 10014.6
  },
  "ticker_spinner_v0_3_diffusers.stl": {
    "watertight": true,
    "body_count": 4,
    "bounds_mm": [
      [
        -46.1,
        -46.1,
        0.0
      ],
      [
        46.1,
        46.1,
        1.25
      ]
    ],
    "extents_mm": [
      92.2,
      92.2,
      1.25
    ],
    "volume_mm3": 320.7
  },
  "ticker_spinner_v0_3_finger_cap_bottom.stl": {
    "watertight": true,
    "body_count": 1,
    "bounds_mm": [
      [
        -11.0,
        -10.998,
        0.0
      ],
      [
        11.0,
        10.998,
        7.6
      ]
    ],
    "extents_mm": [
      22.0,
      21.996,
      7.6
    ],
    "volume_mm3": 1281.32
  },
  "ticker_spinner_v0_3_finger_cap_top.stl": {
    "watertight": true,
    "body_count": 1,
    "bounds_mm": [
      [
        -11.0,
        -10.998,
        -4.8
      ],
      [
        11.0,
        10.998,
        2.8
      ]
    ],
    "extents_mm": [
      22.0,
      21.996,
      7.6
    ],
    "volume_mm3": 1293.39
  },
  "ticker_spinner_v0_3_pcb_envelope.stl": {
    "watertight": true,
    "body_count": 1,
    "bounds_mm": [
      [
        -47.999,
        -47.999,
        -0.0
      ],
      [
        47.999,
        47.999,
        1.0
      ]
    ],
    "extents_mm": [
      95.998,
      95.998,
      1.0
    ],
    "volume_mm3": 2015.13
  },
  "ticker_spinner_v0_3_tip_led_board_envelope.stl": {
    "watertight": true,
    "body_count": 1,
    "bounds_mm": [
      [
        -3.5,
        -6.8,
        0.0
      ],
      [
        3.5,
        6.8,
        0.6
      ]
    ],
    "extents_mm": [
      7.0,
      13.6,
      0.6
    ],
    "volume_mm3": 57.12
  },
  "ticker_spinner_v0_3_top.stl": {
    "watertight": true,
    "body_count": 1,
    "bounds_mm": [
      [
        -49.999,
        -49.999,
        -0.0
      ],
      [
        49.999,
        49.999,
        8.0
      ]
    ],
    "extents_mm": [
      99.998,
      99.998,
      8.0
    ],
    "volume_mm3": 8806.16
  }
}
```

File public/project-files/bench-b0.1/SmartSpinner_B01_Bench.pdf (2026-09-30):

SmartSpinner B0.1 • Только неподвижный стенд • На железе не проверено | 1

# Умный спиннер для трейдера

# B0.1 / Документация настольного стенда

29 сентября 2026 • ручная опытная сборка • один эквивалент луча

Решение: сначала собираем неподвижную электронику. Покупаем небольшую партию компонентов, запускаем один RGB, затем расширяем до 32 RGB. После измерений выбираем миниатюрный LED и проектируем компактную плату. Купленный голограф пока остаётся неизменённым образцом для сравнения.

Что входит

Список покупок, электрическая схема питания и управления, распиновка всех драйверов, 96 соединений с LED, прошивка UNO, порядок пайки, контрольные точки, тесты и незаполненный протокол измерений. В архиве есть редактируемые исходники и результаты программных проверок.

Что этот стенд докажет

Работу отдельного драйвера SM16306SJ и цепочки из шести; адресацию 20 + 12 RGB; приблизительно 5 мА на канал; принудительное гашение; передачу 96 бит; наличие управляемых коротких световых импульсов. Это полезный промежуточный шаг, но не доказательство готовности конечного спиннера.

Что он не докажет

Читаемость картинки при вращении, качество миниатюрных LED, работу BLE и Hall, энергопотребление готового аккумуляторного устройства, четыре луча одновременно, прочность и балансировку. Эти испытания требуют других образцов. Честный статус на выпуске пакета: собрано на компьютере, компилируется; физически не испытано.

Почему Arduino и крупные LED

UNO R3 на ATmega328P - удобный 5-вольтовый генератор сигналов для стола. Конечный контроллер пока не заменяем: nRF52 надо проверять отдельно. Выводные RGB 5 мм легче спаять и перепроверить, но их оптику нельзя переносить на LED порядка 1-2 мм. Размещение 20 + 12 здесь логическое, не геометрическое.

Границы безопасности

Только стационарная низковольтная сборка. Никаких аккумуляторов, открытых сетевых цепей, мотора и изменений китайского ротора. Никаких проводов к вращающейся плате. Переключатель S1=OFF и снятие LED-питания предшествуют любой перепайке и загрузке прошивки. Паяльник, вытяжка и ESD-предосторожности - у сборщика.

SmartSpinner B0.1 • Только неподвижный стенд • На железе не проверено | 2

# 1. Архитектура и расчёт

Узел | Принято для B0.1
Контроллер | Arduino UNO R3, ATmega328P, 16 MHz, логика 5 V
Драйвер | 6 × Sunmoon SM16306SJ, QSOP24, шаг 0.635 мм
LED | 32 × Kingbright WP154A4SEJ3VBDZGW/CA, общий анод
Ток задания | R1-R6 = 3.74 кОм, 1%, около 4.97 мА на канал
Силовое питание | Лабораторный источник 5.00 V с ограничением тока
Логическое питание | USB → UNO → +5V_LOGIC; не соединять с плюсом источника LED
Управление | SPI MODE0, MSB first; SDI, CLK, LE, активный низкий OE
Яркость | В этой прошивке включено/выключено и короткие импульсы; не полноцветный POV

Расчёт, не измерение: Iканала = 18600 / 3740 = 4.97 мА [S1]. Для одного RGB белый означает три включённых канала: 14.9 мА. 96 каналов: около 0.477 A и 2.39 W от линии LED 5 V. Потребление UNO и логики идёт отдельно через USB. Это не прогноз времени работы конечного аккумулятора.

SM16306SJ - 16-канальный токовый сток: он замыкает катоды на землю с ограничением тока. Встроенного независимого PWM для каждого цвета здесь нет. Полутон потребует временного управления, отдельной прошивки и бюджета таймингов. Число каналов - не число RGB: 32 × 3 = 96 = 6 × 16.

На одном драйвере при 16 каналах по 5 мА и условном падении на LED 1.8 V выделилось бы около 0.26 W: (5 - 1.8) × 0.005 × 16, плюс логика. Это консервативная оценка для проверки нагрева, не тепловая аттестация корпуса.

Начальная частота SPI - 125 kHz. 96 тактов занимают 768 мкс без накладных расходов; при 1 MHz - 96 мкс; при 4 MHz - 24 мкс. Фактическое время больше. Эти цифры не равны частоте кадров и не включают цветовые битовые плоскости. На длинных монтажных проводах высокая частота не гарантирована.

Порог перехода дальше: все 96 каналов проходят WALK, ток и гашение в норме, на осциллографе нет ложных вспышек при сдвиге, оптический импульс измерен. Затем нужна миниатюрная тестовая PCB с выбранным малым RGB и целевым контроллером.

SmartSpinner B0.1 • Только неподвижный стенд • На железе не проверено | 3

# 2. Что купить: электроника и монтаж

Количество «купить» включает небольшой запас. Наличие и доставка конкретному покупателю не гарантированы; это спецификация, не оформленная корзина. Ссылки S1-S6 - в конце.

Позиция | В схеме / купить

Точное требование

A1 | 1 / 1 | Arduino UNO R3 A000066 либо совместимая ATmega328P 5 V 16 MHz; USB-кабель передачи данных
U1-U6 | 6 / 10 | SM16306SJ, QSOP24. Не SM16306 без проверки суффикса. LCSC C2830324 [S4]
Переходники | 6 / 8 | Proto-Advantage PA0030 [S6] или сверенный аналог QSOP24 → DIP24. Шаг ИС 0.635 мм; тело 8.2-9.2 × 3.6-4.2 мм, размах ножек 5.6-6.5 мм
D1-D32 | 32 / 40 | WP154A4SEJ3VBDZGW/CA, 5 мм, общий анод, выводы 1.27 мм [S2]
R1-R6 | 6 / 10 | 3.74 кОм, 1%, металл-плёночные, 0.25 W; отдельный резистор на каждый драйвер
R7-R9 | 3 / 10 | 47 Ом, 0.25 W, последовательные в MOSI/CLK/LE у UNO
R10 | 1 / 5 | 100 Ом, 0.25 W, между D9 UNO и RUN-контактом S1
R11 | 1 / 5 | 10 кОм, 0.25 W, подтяжка OE_BUS к +5V_LOGIC
C1-C6, C9 | 7 / 15 | 100 нФ, керамика X7R, ≥16 V, выводные или на переходнике
C7 | 1 / 2 | 10 мкФ, электролит ≥10 V, логика; соблюдать полярность
C8 | 1 / 2 | 100 мкФ, электролит ≥10 V, LED-питание; соблюдать полярность
S1 | 1 / 2 | SPDT ON-ON, break-before-make; OFF = высокий OE; ≥12 V DC 1 A
S2 | 1 / 1 | SPST ON-OFF ≥12 V DC 1 A; разрыв плюса LED-питания
F1 + держатель | 1 / 3 вставки | Плавкая вставка 0.75 A, явно рассчитанная минимум на 12 V DC; изолированный держатель
Монтаж | 1 набор | 2 перфоплаты примерно 100 × 150 мм, изолированные провода AWG24-26 сигнал / AWG22 питание, клеммы, гребёнки, термоусадка, стойки

Стоп перед оплатой: переходник TSSOP24 с шагом 0.65 мм нельзя считать равнозначным QSOP24 0.635 мм. Запросить чертёж площадок; простой надписи «SOP24» недостаточно. При финальной проверке 29.09 LCSC показывал SM16306SJ в наличии, минимум 5 штук, кратность 5. Это не подтверждение доставки в Россию или итоговой цены. При отсутствии у выбранного продавца не заказывать случайную замену.

Проверять LED именно с суффиксом /CA. Модель WP154A4SUREQBFZGC имеет другую полярность и не является заменой. Даже подходящий общий анод с другой распиновкой требует изменения таблицы проводов. TLC59283 не подставлять вместо SM16306SJ с тем же R_EXT: у него другая формула задания тока.

SmartSpinner B0.1 • Только неподвижный стенд • На железе не проверено | 4

# 3. Что купить или одолжить: измерения

Что | Количество | Для чего / требование
Лабораторный источник | 1 | Стабилизация 5 V, режим CC, настройка лимита от 0.03 до 0.60 A, выход OFF, показания V/A; гальванически изолированный от сети штатный прибор
Осциллограф | 1, можно одолжить | ≥2 канала, ≥50 MHz, ≥100 MS/s, два щупа ×10. Нужен для импульсов, не обязателен для первого статического включения
BPW34 Vishay | 1 / купить 2 | Выводной фотодиод для регистрации света; не фоторезистор и не медленный модуль с компаратором
R12 | 1 / 5 | 10 кОм, 0.25 W, нагрузка фотодиода
R13 | 1 / 5 | 1 кОм, 0.25 W; ставится ВМЕСТО R12 при насыщении, не одновременно
R14 | 1 / 5 | 470 Ом, 0.25 W; только для отдельной проверки LED до монтажа
Датчик температуры | 1 | Контактная термопара с прибором или подходящий мультиметр; для проверки нагрева, не оценивать пальцем
Расходники | по наличию | Флюс для электроники, тонкий припой, оплётка, лупа, пинцет, очиститель по флюсу, матовый чёрный экран фотодиода

Паяльник и мультиметр у тебя уже есть. Осциллограф разумно сначала одолжить. Логический анализатор полезен дополнительно, но не заменит измерение светового импульса и аналоговых фронтов. Телефонное видео тоже не заменяет осциллограф.

Можно купить сейчас: UNO R3, источник (если нет), перфоплаты и расходники. Сначала сверить карточку: точные драйверы, LED и переходники. Пока не покупать: батареи, зарядку, мотор, подшипник для стенда, корпус и производственную партию спиннерных PCB.

Подбор магазина и цены - отдельный шаг: доставка, стоимость всего комплекта и карточки переходников пока не подтверждены. Перед оплатой сверить точные артикулы, геометрию и комплектацию.

Что прислать до первого включения

Фото маркировки драйвера; фото его пайки с обеих сторон; фото карточки и распиновки LED; общую сборку сверху/снизу; измеренные сопротивления R1-R6; результаты прозвонки питания. По этим данным можно проверить соответствие пакету, но фотографии не заменяют электрические измерения.

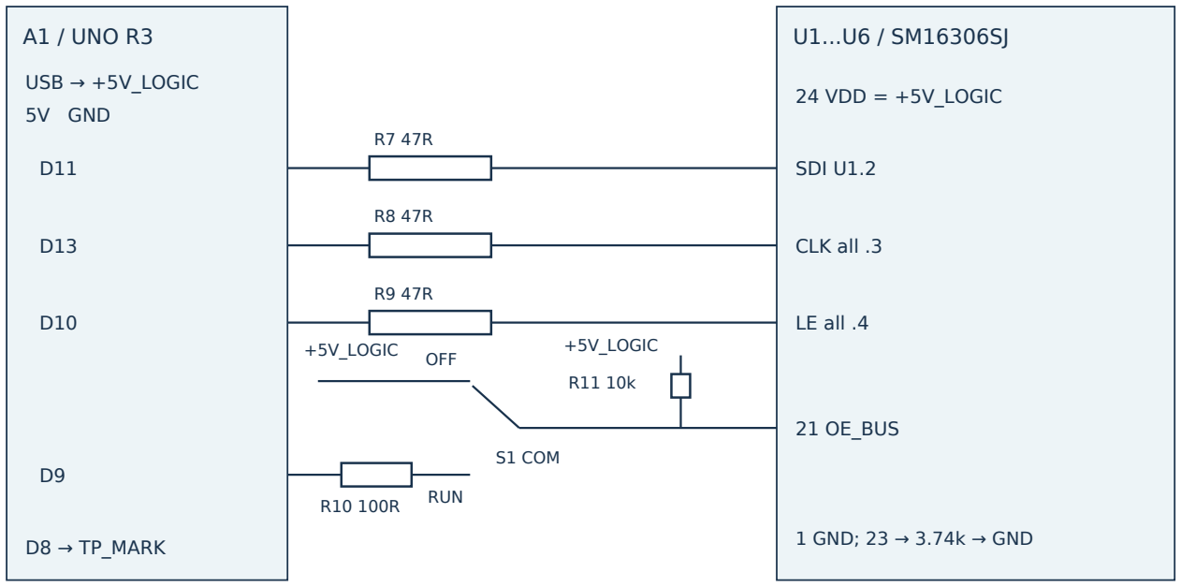
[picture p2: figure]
A1 / UNO R3; USB → +5V_LOGIC; 5V GND; SDI U1.2; CLK all .3; LE all .4; 24 VDD = +5V_LOGIC; 1 GND; 23 → 3.74k → GND; RUN; OFF +5V_LOGIC; S1 COM; 21 OE_BUS; +5V_LOGIC; D8 → TP_MARK

SmartSpinner B0.1 • Только неподвижный стенд • На железе не проверено | 5

# 4. Схема питания и управления

Цепочка: U1.22 → U2.2; U2.22 → U3.2; ...; U5.22 → U6.2; U6.22 → TP_SDO

PS1 / 5.00 V CC

+ - → GND

F1 0.75A

S2
+5V_LED D1...D32 / common anode

pin2 → +5V_LED; R(pin1)/G(4)/B(3) → OUT

C8 100u + C9 100n → GND

Раздельные плюсы питания. Общий GND. S1=OFF; S2=OFF.

Плюсы двух источников не соединяются. Общая земля объединяет GND UNO, GND U1-U6, минус лабораторного источника и точки GND измерений. Ток LED возвращать к минусу источника по отдельной толстой шине; не через тонкий провод до UNO.

S1 - физический запрет света: COM подключается к OE_BUS, OFF к +5V_LOGIC, RUN к D9 через R10. R11 подтягивает OE_BUS к +5V_LOGIC. В OFF выход UNO отключён от шины переключателем. Нельзя заменить эту схему перемычкой, которая закоротит выход UNO на +5 V.

C1-C6 = 100 нФ между pin24 и pin1 каждого драйвера, максимально близко. C7 = 10 мкФ на +5V_LOGIC. C8 = 100 мкФ и C9 = 100 нФ на +5V_LED после S2. F1 ограничивает последствия повреждения проводки, но не заменяет электронный лимит тока источника.

На внешнем источнике выставить 5.00 V до подключения. Подавать сначала логику USB при S1=OFF и S2=OFF, затем включать силовой источник и S2. Выключать: S1=OFF, S2=OFF, источник OFF, затем USB. Не оставлять LED-питание включённым при обесточенной логике.

SmartSpinner B0.1 • Только неподвижный стенд • На железе не проверено | 6

# 5. Точная распиновка драйверов

Нумерация U1-U6 идёт от UNO к дальнему концу цепочки. Номера ниже - номера выводов корпуса, не маркировка неизвестного переходника. Найти метку pin1, прозвонить каждую площадку на DIP-вывод. Вид и ориентация корпуса - S1, страница 1. Для другого корпуса эта таблица недействительна.

Вывод SM16306SJ | Сигнал | Соединение
1 | GND | Общая земля
2 | SDI | U1: MOSI через R7; U2-U6: SDO предыдущего драйвера
3 | CLK | Общая CLK_BUS от UNO D13 через R8
4 | LE | Общая LE_BUS от UNO D10 через R9
5-20 | OUT0-OUT1
| 5 | Катоды LED по таблице следующих страниц; pin = OUT + 5
21 | OE | Общая OE_BUS от COM S1; высокий уровень гасит
22 | SDO | U1-U5: pin2 следующего; U6: только точка TP_SDO
23 | R_EXT | Свой R1...R6 3.74 кОм на GND; не объединять pin23 разных ИС
24 | VDD | +5V_LOGIC, свой C1...C6 100 нФ на pin1

Провода управления делать короткими; общая длина шины по возможности до 15-20 см, рядом вести землю. Не устраивать звезду из длинных отводов CLK. R7-R9 разместить у UNO. Начинать на 125 kHz; после измерений пробовать 1 MHz, затем 4 MHz. При сбоях не повышать питание: укоротить монтаж и проверить сигнал.

Сериализация: сначала 16 бит U6, затем U5...U1; каждый блок от bit15 к bit0. Последние 16 бит остаются в ближайшем U1. Bit0 управляет OUT0. Во время передачи OE высокий; после 96 тактов LE поднимается и опускается, только затем разрешается свет. В этой прошивке новые данные не сдвигаются при открытых выходах.

Один RGB: электрическое соединение

У выбранного Kingbright общий анод pin2 идёт на +5V_LED. Катоды: R=pin1, G=pin4, B=pin3. Дополнительных токоограничительных резисторов последовательно с LED в основном стенде нет: ток задаёт драйвер. Это не относится к отдельному тесту ножек через R14=470 Ом.

Шаг ножек LED 1.27 мм, а перфоплаты обычно 2.54 мм. Аккуратно развести ножки инструментом, удерживая их ниже корпуса; не сгибать у эпоксидной линзы, оставить не менее 3 мм. Все неизолированные перекрещивающиеся ножки закрыть термоусадкой.

SmartSpinner B0.1 • Только неподвижный стенд • На железе не проверено | 7

# 6. Соединения LED: верхние 20

Пиксель в команде PIX начинается с 0, обозначение D - с 1. Обозначение U2.8 означает вывод 8 микросхемы U2. Все аноды pin2 D1-D32 соединены с +5V_LED. G и B намеренно не идут по порядку физических ножек.

LED / PIX | Банк | R: pin1 | G: pin4 | B: pin3
D1 / 0 | TOP | U1.5 (CH 0) | U1.6 (CH 1) | U1.7 (CH 2)
D2 / 1 | TOP | U1.8 (CH 3) | U1.9 (CH 4) | U1.10 (CH 5)
D3 / 2 | TOP | U1.11 (CH 6) | U1.12 (CH 7) | U1.13 (CH 8)
D4 / 3 | TOP | U1.14 (CH 9) | U1.15 (CH 10) | U1.16 (CH 11)
D5 / 4 | TOP | U1.17 (CH 12) | U1.18 (CH 13) | U1.19 (CH 14)
D6 / 5 | TOP | U1.20 (CH 15) | U2.5 (CH 16) | U2.6 (CH 17)
D7 / 6 | TOP | U2.7 (CH 18) | U2.8 (CH 19) | U2.9 (CH 20)
D8 / 7 | TOP | U2.10 (CH 21) | U2.11 (CH 22) | U2.12 (CH 23)
D9 / 8 | TOP | U2.13 (CH 24) | U2.14 (CH 25) | U2.15 (CH 26)
D10 / 9 | TOP | U2.16 (CH 27) | U2.17 (CH 28) | U2.18 (CH 29)
D11 / 10 | TOP | U2.19 (CH 30) | U2.20 (CH 31) | U3.5 (CH 32)
D12 / 11 | TOP | U3.6 (CH 33) | U3.7 (CH 34) | U3.8 (CH 35)
D13 / 12 | TOP | U3.9 (CH 36) | U3.10 (CH 37) | U3.11 (CH 38)
D14 / 13 | TOP | U3.12 (CH 39) | U3.13 (CH 40) | U3.14 (CH 41)
D15 / 14 | TOP | U3.15 (CH 42) | U3.16 (CH 43) | U3.17 (CH 44)
D16 / 15 | TOP | U3.18 (CH 45) | U3.19 (CH 46) | U3.20 (CH 47)
D17 / 16 | TOP | U4.5 (CH 48) | U4.6 (CH 49) | U4.7 (CH 50)
D18 / 17 | TOP | U4.8 (CH 51) | U4.9 (CH 52) | U4.10 (CH 53)
D19 / 18 | TOP | U4.11 (CH 54) | U4.12 (CH 55) | U4.13 (CH 56)
D20 / 19 | TOP | U4.14 (CH 57) | U4.15 (CH 58) | U4.16 (CH 59)

Формула для проверки: канал c = 3 × pixel + color, где R=0, G=1, B=2. Драйвер U = floor(c/16)+1, его вывод = (c mod 16)+5. У некоторых RGB три цвета приходят на разные драйверы - это нормально, поскольку 16 не делится на 3.

Каждую строку отмечать после прозвонки в wiring.html или в распечатке. Не полагаться только на цвет монтажного провода. Полная машиночитаемая таблица лежит в wiring.json.

SmartSpinner B0.1 • Только неподвижный стенд • На железе не проверено | 8

# 7. Соединения LED: торцевые 12

Эти LED тоже неподвижны и лежат на столе. Таблица проверяет 12 логических пикселей торца, но не высоту будущего цилиндрического экрана. У всех LED общий анод pin2 идёт на +5V_LED.

LED / PIX | Банк | R: pin1 | G: pin4 | B: pin3
D21 / 20 | TIP | U4.17 (CH 60) | U4.18 (CH 61) | U4.19 (CH 62)
D22 / 21 | TIP | U4.20 (CH 63) | U5.5 (CH 64) | U5.6 (CH 65)
D23 / 22 | TIP | U5.7 (CH 66) | U5.8 (CH 67) | U5.9 (CH 68)
D24 / 23 | TIP | U5.10 (CH 69) | U5.11 (CH 70) | U5.12 (CH 71)
D25 / 24 | TIP | U5.13 (CH 72) | U5.14 (CH 73) | U5.15 (CH 74)
D26 / 25 | TIP | U5.16 (CH 75) | U5.17 (CH 76) | U5.18 (CH 77)
D27 / 26 | TIP | U5.19 (CH 78) | U5.20 (CH 79) | U6.5 (CH 80)
D28 / 27 | TIP | U6.6 (CH 81) | U6.7 (CH 82) | U6.8 (CH 83)
D29 / 28 | TIP | U6.9 (CH 84) | U6.10 (CH 85) | U6.11 (CH 86)
D30 / 29 | TIP | U6.12 (CH 87) | U6.13 (CH 88) | U6.14 (CH 89)
D31 / 30 | TIP | U6.15 (CH 90) | U6.16 (CH 91) | U6.17 (CH 92)
D32 / 31 | TIP | U6.18 (CH 93) | U6.19 (CH 94) | U6.20 (CH 95)

Измерительный фотодиод, необязательный для статического запуска

+5V_LOGIC

K

A

TP_LIGHT → CH2 ×10

R12 10k → GND

UNO D8 → CH1 ×10

Земли щупов → GND

PD1 BPW34. R13 1k заменяет R12 только при насыщении. Не измеритель люкс.

BPW34: катод K к +5V_LOGIC, анод A к TP_LIGHT; R12=10 кОм от TP_LIGHT к GND. Это обратное смещение, не схема питания обычного LED. Катодную метку сверить с чертежом Vishay S3, страница 4. Щуп CH2 ×10 - TP_LIGHT, земля щупа - GND. CH1 - UNO D8 (MARK), земля - GND.

Разместить фотодиод в нескольких сантиметрах от одного LED, экранировать от комнатного света. Если сигнал близок к 5 V и обрезан - уменьшить засветку или заменить R12 на R13=1 кОм. Это датчик формы импульса, а не калиброванный измеритель яркости. Не подключать его к 12 V блока голографа.

SmartSpinner B0.1 • Только неподвижный стенд • На железе не проверено | 9

# 8. Сборка: до подачи питания

G0. Проверка комплектации. Сверить модели, суффиксы и геометрию переходников. Выписать фактические pin1, LED-анод и цвета ножек. Непонятная маркировка или отсутствие даташита - остановка, не догадка.

### 1. Подготовить монтаж. Подписать A1, U1-U6 и D1-D32 на основании. Разделить зону

логики/драйверов и зону LED. Поставить платы на непроводящие стойки. Не оставлять их на металлическом столе. Финальное расположение 5-мм LED может быть 4 × 8, а не узкой длинной линейкой.

### 2. Припаять только U1 на переходник. Проверить ориентацию, отсутствие мостов под

лупой, прозвонить все 24 вывода до контактов переходника. Припаять C1 и R1 рядом. Записать сопротивление R1 до установки: 3.74 кОм ±1%, то есть примерно 3.70-3.78 кОм.

### 3. Смонтировать питание и запрет света. S1, S2, F1, R7-R11, C7-C9, клеммы и контрольные

точки. Пока без UNO и источника проверить: S1 OFF соединяет COM с +5V_LOGIC и разъединяет COM с D9; S1 RUN соединяет COM через R10 с D9. S2 OFF разрывает плюс LED. Не выбирать положения по внешнему направлению рычажка - прозвонить.

### 4. Проверить один LED отдельно. Источник 5.00 V, лимит 0.02 A. Анод pin2 к плюсу. Через

R14=470 Ом поочерёдно соединить каждый предполагаемый катод с минусом; записать R/G/B. Никогда не подключать LED прямо поперёк питания. Снять питание после теста. Если модель не совпала с таблицей, не продолжать пайку по ней.

5. Подключить D1 к U1. D1.1 → U1.5, D1.4 → U1.6, D1.3 → U1.7, D1.2 → +5V_LED. Незадействованные OUT пока оставить свободными, не замыкать на землю. Остальные пять драйверов можно добавить после G1: первые тесты используют только U1, последние 16 бит пакета предназначены ему.

G1. Прозвонка без питания. Проверить GND, разделение плюсов, полярность электролитов, R_EXT и все четыре ножки D1. Между питанием и GND не должно быть постоянного короткого замыкания; заряд конденсаторов может дать краткую индикацию. Показания низкого сопротивления после установления требуют расследования. Не прикладывать омметр к запитанной схеме.

Подключать амперметр только последовательно и только при снятом питании. Не ставить его поперёк источника. Предпочтительно пользоваться показанием тока источника; для точного тока одного канала нужен последовательный мультиметр с исправным предохранителем.

SmartSpinner B0.1 • Только неподвижный стенд • На железе не проверено | 10

# 9. Первое включение и расширение

### 6. Загрузить прошивку. S1=OFF, S2=OFF, внешний источник отключён. Подключить UNO по

USB, выбрать Arduino Uno и файл firmware/spinner_bench/spinner_bench.ino. Загрузить. Открыть Serial Monitor 115200 / Newline. Должна появиться строка B0.1. Отправить OFF.

G2. Логика. Мультиметром проверить +5V_LOGIC относительно GND: 4.75-5.25 V. OE_BUS при S1=OFF должен быть близок к +5V_LOGIC. Перевести S1=RUN без команды свечения: OE_BUS остаётся высоким. Вернуть S1=OFF. При ином результате LED-питание не включать.

7. Один красный канал. На отключённом выходе источника установить 5.00 V, лимит 0.03 A. Включить выход и S2 при S1=OFF: D1 должен быть тёмным. S1=RUN, отправить CH 0. Должен светиться только красный D1, затем сам погаснуть примерно через 5 секунд. Ожидаемый ток LED-питания около 5 мА. Повторить CH 1 и CH 2: зелёный и синий. PIX 0 7 - белый, около 15 мА.

G3. Порог остановки. Один канал вне 4.0-6.0 мА после учёта разрешения прибора, два светящихся канала вместо одного, ток покоя LED выше 2 мА, устойчивый режим CC, запах, шум источника или быстрое нагревание - OFF и диагностика. Нельзя лечить это увеличением лимита. Допуск 4-6 мА - наш широкий приёмочный коридор прототипа, не паспортная точность ИС.

8. Физический запрет. Во время CH 0 переключить S1 в OFF: свет должен исчезнуть сразу. Проверить возврат в RUN после завершения тайм-аута: свет не возвращается. Кнопка Reset UNO при S1=OFF не должна давать вспышку. Проверку отсутствия очень коротких вспышек при S1=RUN проводить фотодиодом, а не только глазом.

### 9. Расширить до шести драйверов. Снять всё питание по порядку. Установить U2-U6, их

резисторы и конденсаторы; соединить SDO → SDI, общие CLK/LE/OE и питание. Подключить D2-D32 по матрице, прозвонить каждый канал. Повторить G1-G2. Лимит источника сначала 0.03 A: WALK включает только один канал за раз.

### 10. Общая нагрузка. После успешного WALK установить источник OFF, лимит 0.60 A, затем

включить. ALL 1/2/4 дают около 0.159 A, ALL 7 около 0.477 A. Каждая команда ALL длится только 0.5 s. Для показания медленного прибора использовать режим фиксации или осциллограф; не выдавать колеблющееся показание за точное измерение. Не устраивать длительный прогон белым до оценки нагрева.

SmartSpinner B0.1 • Только неподвижный стенд • На железе не проверено | 11

# 10. Прошивка и команды

Все команды латиницей, ЗАГЛАВНЫМИ, с Newline. Маска: R=1, G=2, B=4; сумма включает сочетания, 7 - все три цвета. Индекс PIX 0-31; канал CH 0-95. Перед каждой командой прошивка гасит выходы и очищает регистр.

Команда | Действие / ограничение
HELP | Напечатать справку; выходы погашены
OFF | Погасить выходы и записать нули; питание не отключает
CH 0 | Только D1 R, 5 секунд; CH 95 = D32 B
PIX 20 3 | Первый торцевой D21, красный + зелёный, 5 секунд
ALL 7 | Все RGB белым, максимум 0.5 секунды
WALK | По одному каналу 0...95, 150 мс на канал, затем OFF
PULSE 0 50 | Канал 0, номинально 50 мкс, период около 2 мс, 5 секунд
SPEED 1000000 | SPI 1 MHz; свет выключен; новая скорость действует до Reset

Скорости: 125000, 250000, 500000, 1000000, 2000000, 4000000 Hz. После Reset снова 125000 Hz. Диапазон PULSE: канал 0-95, ширина 20-500 мкс. Ошибочная завершённая команда и переполнение входной строки гасят выходы. Частичная незавершённая строка не отменяет тайм-аут текущего теста.

D8 MARK высокий во время программного разрешения импульса; физический S1 OFF может всё равно держать LED погашенным. Это полезно для тестирования запрета. PULSE не загружает новую картинку каждую вспышку: данные загружаются один раз, затем переключается OE. Он проверяет гашение и оптику, а не всю полосу цветного POV.

На время короткого импульса прерывания отключаются. Реальная ширина включает накладные расходы кода; период не является прецизионным. Измерить, записать результат и джиттер. В этой версии нет аппаратного watchdog, обратной связи по току, термозащиты, автообнаружения числа драйверов и производственного кода отображения.

Важное ограничение: компиляция, тест упаковки битов и проверка парсера выполнены на компьютере; это не доказывает реальные уровни и тайминги на конкретном UNO и монтаже. HEX предназначен только для указанной платы. Для загрузки проще использовать исходный .ino и Arduino IDE.

SmartSpinner B0.1 • Только неподвижный стенд • На железе не проверено | 12

# 11. План испытаний и критерии приёмки

Тест | Как проверить | Условие продолжения
T01 Питание | Мультиметр, G2 | Оба питания 4.75-5.25 V, плюсы разделены
T02 Гашение | OFF, S1 OFF/RUN, Reset | Нет света; ток линии LED менее 2 мА; импульсы отдельно осциллографом
T03 Один канал | CH 0, 1, 2 | Верный цвет; 4.0-6.0 мА на канал
T04 Адресация | WALK + матрица, все 96 | Нет перестановок, пропусков, одновременных лишних каналов
T05 Нагрузка | ALL 1/2/4/7, 0.5 s | Нет CC и просадки ниже 4.75 V; ток согласуется с числом каналов ±15%
T06 Тайм-аут | CH и PIX, затем ALL | Гашение примерно через 5 s и 0.5 s; S1 гасит независимо от команд
T07 Обмен | CLK/LE/OE, 125 kHz → 1 MHz → 4 MHz | 96 тактов, LE после передачи, OE высокий во время сдвига; данные стабильны на положительном фронте
T08 Свет | Фотодиод; PULSE 0 20/50/100 | Один световой импульс на MARK, без паразитных; записаны длительность, задержка и разброс

Для T07 использовать несколько захватов двухканальным прибором: CLK+LE, CLK+SDI, LE+OE. Земли щупов только на GND, не на OUT или R_EXT. Временные требования сверять с S1; общая демонстрация осциллограммы не заменяет измерение setup/hold.

Для T08 сравнить CH1=MARK и CH2=TP_LIGHT, снять не менее 100 импульсов либо воспользоваться статистикой прибора. Измерять ширину на половине высоты импульса, исключить насыщение фотодиода. Если на 20 мкс импульсы различимы, это хороший результат стенда, но окончательный допуск требует бюджета углового разрешения и целевых оборотов.

Температуру корпуса каждого U измерить до запуска и после серии коротких ALL. Временный консервативный стоп-порог стенда - 50 °C или быстрый рост; это не паспортный абсолютный максимум. Тайм-ауты не отменять ради нагревательного теста. Длительная максимальная нагрузка в B0.1 не квалифицирована.

Не пройденный тест не скрывать. Внести фото, частоту, напряжение, ток и симптом в test_record.md. Сначала исправить причину, затем повторить тест и зависимые проверки. Не переходить к вращению просто потому, что WALK красиво выглядит.

SmartSpinner B0.1 • Только неподвижный стенд • На железе не проверено | 13

# 12. Диагностика и следующий этап

Симптом | Сначала проверить
Не светится ничего | S1/S2; OE; анод LED; общую землю; последний U1-блок данных; правильный MPN
Светятся неверные цвета | Pin1/3/4 LED и маску R=1 G=2 B=4; не менять прошивку до прозвонки
Работает только часть | SDO предыдущего → SDI следующего; пайку pin22/2; расположение U1-U6
Самопроизвольные вспышки | OE pull-up и S1, C1-C6, длину CLK, LE; снизить SPEED до 125000
Ток слишком большой | R_EXT: 3.74 кОм, не Ом; короткие замыкания; не тот драйвер; неверную полярность
Нет сигнала фотодиода | Полярность BPW34, затенение, масштаб CH2, ×10, нагрузку 10 кОм

После настольных испытаний

1. Зафиксировать измерения и выбрать архитектуру управления. Перенести проверенный драйверный интерфейс на целевой nRF52 или другой выбранный контроллер, отдельно проверить обмен при активном BLE.
2. Выбрать точный миниатюрный RGB по datasheet, доступности и измерению образца. Сделать небольшую опытную PCB с реальным шагом и нужным током. Пять миллиметров текущего LED не уменьшаются программно.
3. Проверить миниатюрную линейку неподвижно: ток, оптическую ширину импульса, яркость, нагрев и разводку. Затем рассчитывать ресурс батареи по реальному профилю свечения, а не по числу LED.
4. Спроектировать отдельный закрытый вращательный стенд: удержание платы, независимая балансировка, защита от вылета, ограничение оборотов, питание без свободных вращающихся проводов, синхронизация и аварийный останов. Пуск - только после проверки механики человеком на месте.

Купленный вентилятор: пригоден как визуальный эталон без переделок. Нельзя считать его безопасным держателем неизвестной дополнительной платы. В этом пакете нет чертежа её крепления и разрешения на такой запуск. На 1250 об/мин край радиуса 0.21 м движется примерно 27.5 м/с; добавленная масса и эксцентриситет существенно меняют нагрузки.

Оценка усилий, не обещание срока

После получения деталей: первый U1 и LED - примерно один вечер; полный монтаж и прозвонка
- ещё 1-2 вечера; измерения с осциллографом - отдельная сессия. Это ориентир для человека, умеющего паять QSOP, без учёта доставки и поиска дефектов. Наличие паяльника и мультиметра позволяет начать, но не заменяет осциллограф на этапе временных характеристик.

SmartSpinner B0.1 • Только неподвижный стенд • На железе не проверено | 14

# 13. Источники и статус проверки

Первичные документы проверены 29.09.2026. Фотографии купленного устройства подтверждают маркировку SM16306SJ, но не схему всех цепей и не точный артикул его LED. Производительские PDF не включены в архив, ссылки ведут на оригиналы или зеркало документа производителя.

S1. Sunmoon SM16306SJ, ZOGOSZZ V1.3: pinout pp.1-2, ток R_EXT и режимы, временные диаграммы; QSOP24 p.12. Питание, нумерация выводов, формула тока и полярность OE сверены с этим документом.

https://datasheet.lcsc.com/datasheet/pdf/04503b04317535e2ac7b54c7d35b022f.pdf?productCode=C2830324

S2. Kingbright WP154A4SEJ3VBDZGW/CA, V7A: общий анод pin2, катоды 1/3/4, геометрия и монтаж. Не путать с внешне похожими моделями с общим катодом.

https://www.kingbrightusa.com/images/catalog/SPEC/WP154A4SEJ3VBDZGW-CA.pdf

S3. Vishay BPW34, doc81521: фотодиод и катодная метка p.4.

https://www.vishay.com/docs/81521/bpw34.pdf

S4. LCSC, карточка точного драйвера C2830324. При финальной проверке показывал наличие; минимум 5 штук, кратность 5. Перепроверить при оплате. Доставка и условия для конкретного покупателя не проверены.

https://www.lcsc.com/product-detail/C2830324.html

S5. Arduino UNO R3, официальная распиновка: D11 MOSI, D13 SCK, D10 SS; D9 OE и D8 MARK назначены нами.

https://content.arduino.cc/assets/A000066-full-pinout.pdf

S6. Proto-Advantage PA0030, QSOP24 → DIP24, шаг 0.635 мм. Заказывать вариант с выводами; стандартная гребёнка не обязательно соответствует его монтажу. Геометрию сверять с чертежом на странице производителя; доставка не проверена.

https://proto-advantage.com/store/product_info.php?products_id=2200034

Проверка, проведённая при выпуске

build/verification.txt: результат компиляции для arduino:avr:uno и host-тестов упаковки битов/парсера. tools/verify_wiring.py: полнота 96 соединений, полярность LED, сигнальные и силовые сети, отсутствие объединения двух плюсов. PDF отрендерен и просмотрен. Эти проверки не являются KiCad ERC/DRC, измерением аппаратуры или независимой инженерной приёмкой.

Остаётся физически выполнить: все T01-T08 и проверку температуры; протокол пока пуст. За пределами пакета: производственная PCB, Gerber, CPL, батарея/зарядка, конечная механика, моторный стенд и полноценная прошивка POV. Документы старых версий не получили автоматически статус исправленных.

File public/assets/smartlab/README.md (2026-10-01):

# Визуализации проекта Смартлаба

Выбраны владельцем проекта 01.10.2026:

- «Пульс рынка»: market-detail.png — выбранный вид в руке; market-full.png — полная визуализация с двумя ракурсами.
- «Биржевой сигнал»: signals-detail.png — выбранный вид в руке; signals-full.png — полная визуализация с двумя ракурсами.

Полные изображения созданы встроенным генератором изображений. Файлы detail — предоставленные пользователем снимки выбранных фрагментов, без перерисовки. Из снимков удалены служебные EXIF и текстовые метаданные; пиксели не менялись.

Название «СМАРТЛАБ» нанесено на центральную крышку и присутствует в световом изображении. Это текстовое обозначение проекта, не воспроизведение официального графического логотипа.

Данные демонстрационные. Геометрия, яркость, чёткость, графики и читаемость на этих картинках не являются результатом физических испытаний. Видимый диск обозначает след вращения четырёх лучей. Свечной вариант не выбран и не публикуется.

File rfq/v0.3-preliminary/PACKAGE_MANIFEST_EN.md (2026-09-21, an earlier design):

# SmartSpinner v0.3 — preliminary RFQ package

## Purpose

This package is intended for preliminary DFM discussion, sourcing feedback and a budgetary turnkey-PCBA quotation. It is not a production release.

## Requested quantity

- 10 complete electronic sets for the initial quotation.
- Each set: 1 main four-arm PCB and 4 vertical tip PCBs.
- Total: 10 main PCBs and 40 tip PCBs.
- Please also quote 5-set and 25-set alternatives.

## Available preliminary documentation

- Five-sheet mechanical engineering drawing.
- Parametric enclosure STL and STEP files.
- Main-PCB mechanical outline in DXF.
- Tip-PCB mechanical outline in DXF.
- Main and tip PCB mechanical STEP envelopes.
- Product-level visualizations and partner brief.
- Mechanical validation report and model generator.

## Files not yet released

- Electrical schematic.
- Routed PCB source files.
- Manufacturing Gerber and drill package.
- Final BOM with approved manufacturer part numbers.
- CPL / centroid / pick-and-place data.
- Assembly drawing and polarity map.
- Firmware binary and programming instructions.
- Functional-test procedure.

The missing files will be produced after preliminary supplier feedback. No file in the current package is authorized for production.

## Preliminary architecture

- Four-arm main PCB, approximately 96–100 mm overall diameter.
- 20 top-facing addressable RGB LEDs per arm, 80 total.
- Four vertical tip boards with 12 addressable RGB LEDs each, 48 total.
- nRF52840/BLE.
- Hall sensor plus IMU.
- LiPo charger and 3.3 V / 5 V power conversion.
- Batteries excluded from international shipment.

## Public reference links

- Website: https://germanklimenko.github.io/smartspinner/
- Repository: https://github.com/GermanKlimenko/smartspinner
- Engineering drawing: https://germanklimenko.github.io/smartspinner/project-files/ticker_spinner_v0_3_engineering_drawing.pdf
- Partner brief: https://germanklimenko.github.io/smartspinner/project-files/ticker_spinner_v0_3_partner_brief.pdf
- Complete preliminary package: https://germanklimenko.github.io/smartspinner/project-files/ticker_spinner_v0_3_complete_package.zip

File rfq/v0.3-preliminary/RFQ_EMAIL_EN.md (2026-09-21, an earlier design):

Subject: Preliminary DFM and turnkey PCBA inquiry — SmartSpinner v0.3, 10 complete sets

Hello [COMPANY] PCBA Team,

My name is German Klimenko. I am developing SmartSpinner v0.3, a handheld four-arm persistence-of-vision display with Bluetooth connectivity.

I would like to request a preliminary DFM review and budgetary quotation for 10 complete electronic sets. Each set is expected to include:

- 1 four-arm main PCB, approximately 96–100 mm overall diameter;
- 80 top-facing addressable RGB LEDs, 20 LEDs per arm;
- 4 small vertical tip PCBs;
- 12 addressable RGB LEDs on each tip PCB, 48 tip LEDs per set;
- nRF52840/BLE control;
- Hall sensor and IMU for angular synchronization;
- LiPo charging and 3.3 V / 5 V power circuitry;
- turnkey component sourcing, PCB fabrication, SMT assembly and AOI.

The requested lot therefore contains 10 main PCBs and 40 tip PCBs. Batteries and the 3D-printed enclosure should not be included in the PCBA shipment.

The current v0.3 package is a mechanical and product-level engineering prototype. The PCB outlines and component envelopes are available, but the final schematic, routed PCB, Gerber, BOM and CPL files are still under development. The current files must not be treated as production-ready data.

Project references:

- Project website: https://germanklimenko.github.io/smartspinner/
- Public repository: https://github.com/GermanKlimenko/smartspinner
- v0.3 engineering drawing: https://germanklimenko.github.io/smartspinner/project-files/ticker_spinner_v0_3_engineering_drawing.pdf
- v0.3 partner brief: https://germanklimenko.github.io/smartspinner/project-files/ticker_spinner_v0_3_partner_brief.pdf
- Complete preliminary v0.3 package: https://germanklimenko.github.io/smartspinner/project-files/ticker_spinner_v0_3_complete_package.zip

Please advise:

1. Can you manufacture and assemble this unusual four-arm main PCB and the four vertical tip PCBs?
2. Do you offer electrical schematic and PCB-layout services, or should we provide complete Gerber/BOM/CPL data?
3. Which in-stock addressable RGB LED packages would you recommend for the 80 top LEDs and 48 vertical LEDs?
4. Can the tip boards be supplied as assembled breakaway panels, or should they be delivered individually?
5. What panelization and breakaway-rail requirements would you recommend for automated assembly?
6. Can you source and assemble an nRF52840 module, IMU, Hall sensor, charger and power converter?
7. Can you program the nRF52 and perform a basic functional test if we provide firmware and a test procedure?
8. Please provide preliminary price ranges and lead times for 5, 10 and 25 complete sets.
9. Please separate PCB fabrication, components, assembly, stencil/tooling, programming/testing and shipping in the quotation.
10. Please confirm available delivery options to Moscow, Russia, excluding LiPo batteries.

Our immediate objective is to understand your manufacturing constraints before finalizing the electrical design. After your feedback, we will prepare the production Gerber, BOM, CPL, assembly drawings, firmware and test procedure.

Best regards,
German Klimenko
SmartSpinner project
https://germanklimenko.github.io/smartspinner/

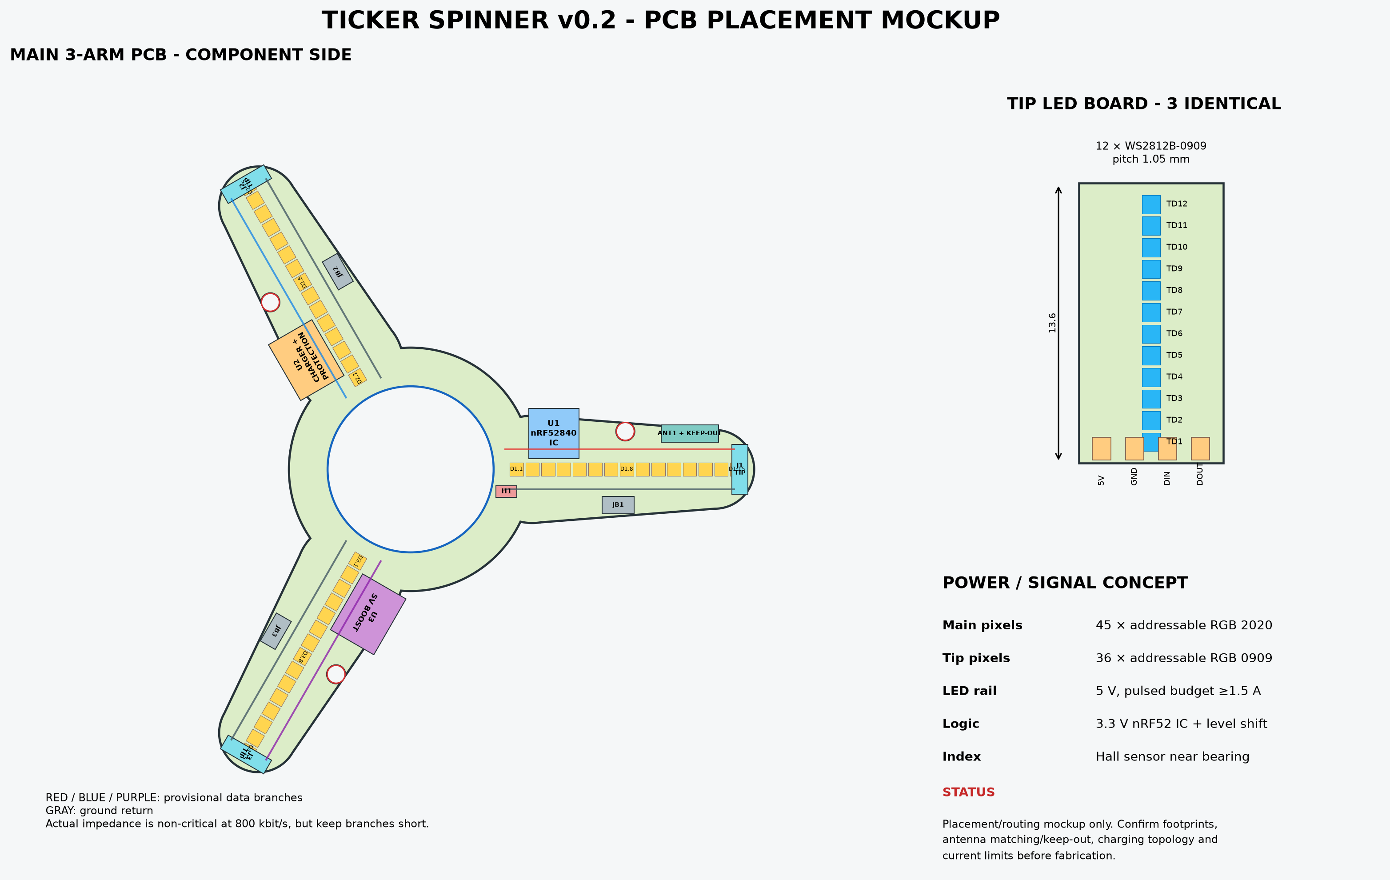
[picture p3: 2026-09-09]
public/assets/pcb-layout.png

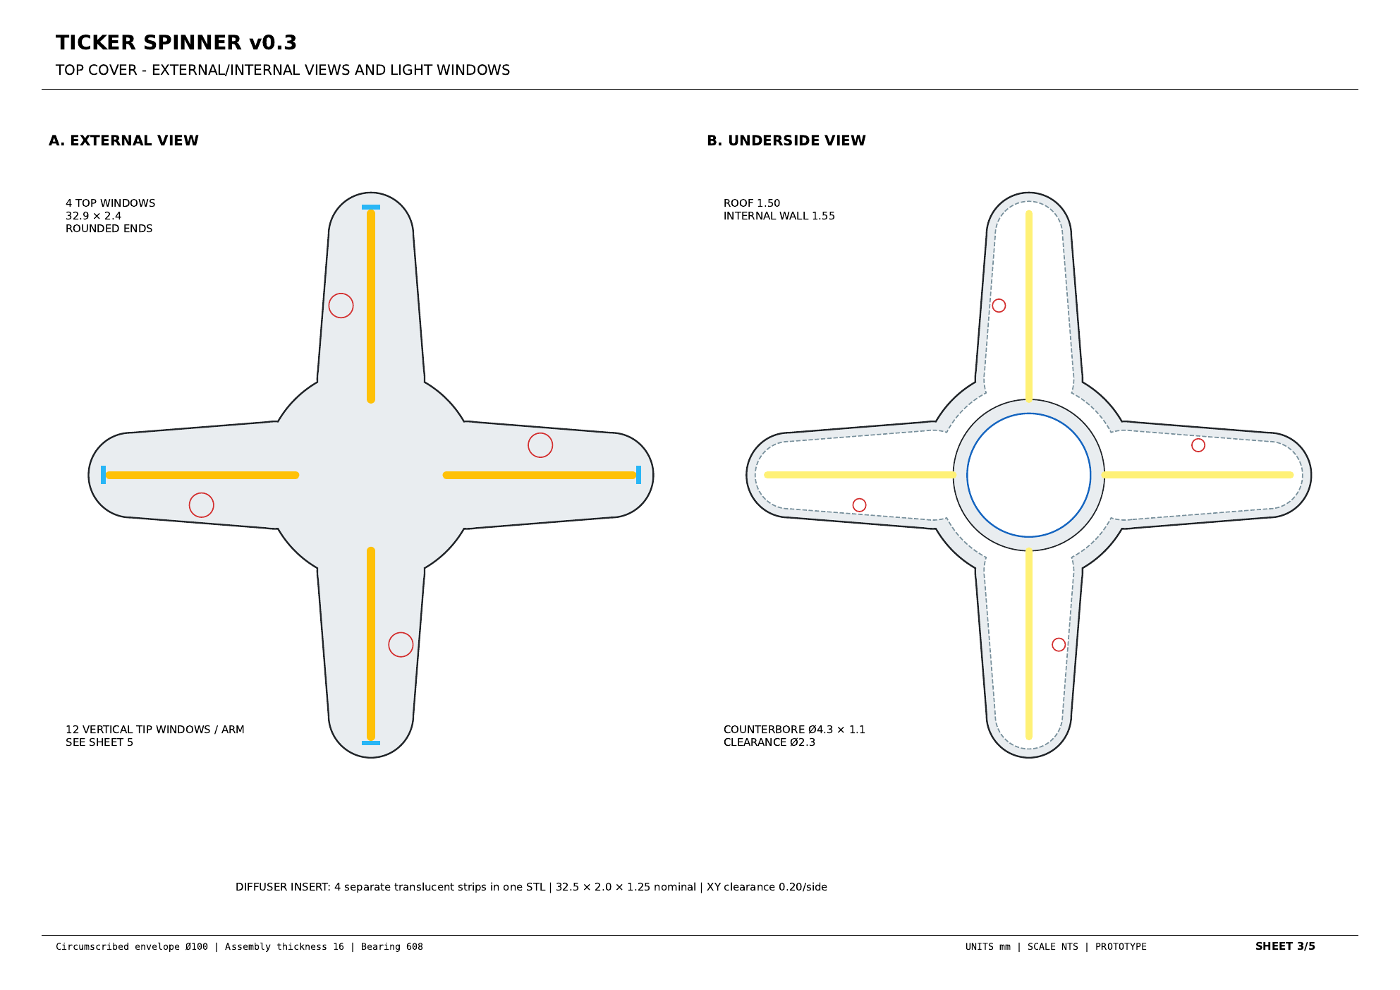
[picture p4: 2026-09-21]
public/assets/drawings/sheet-3.png

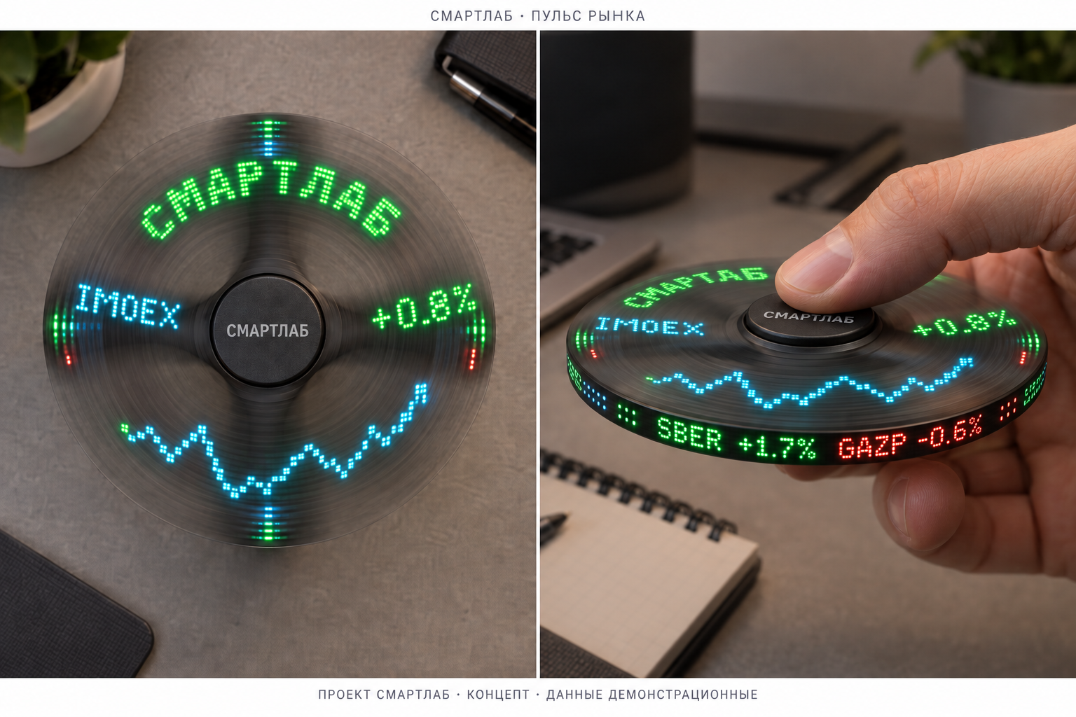
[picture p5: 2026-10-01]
public/assets/smartlab/market-full.png

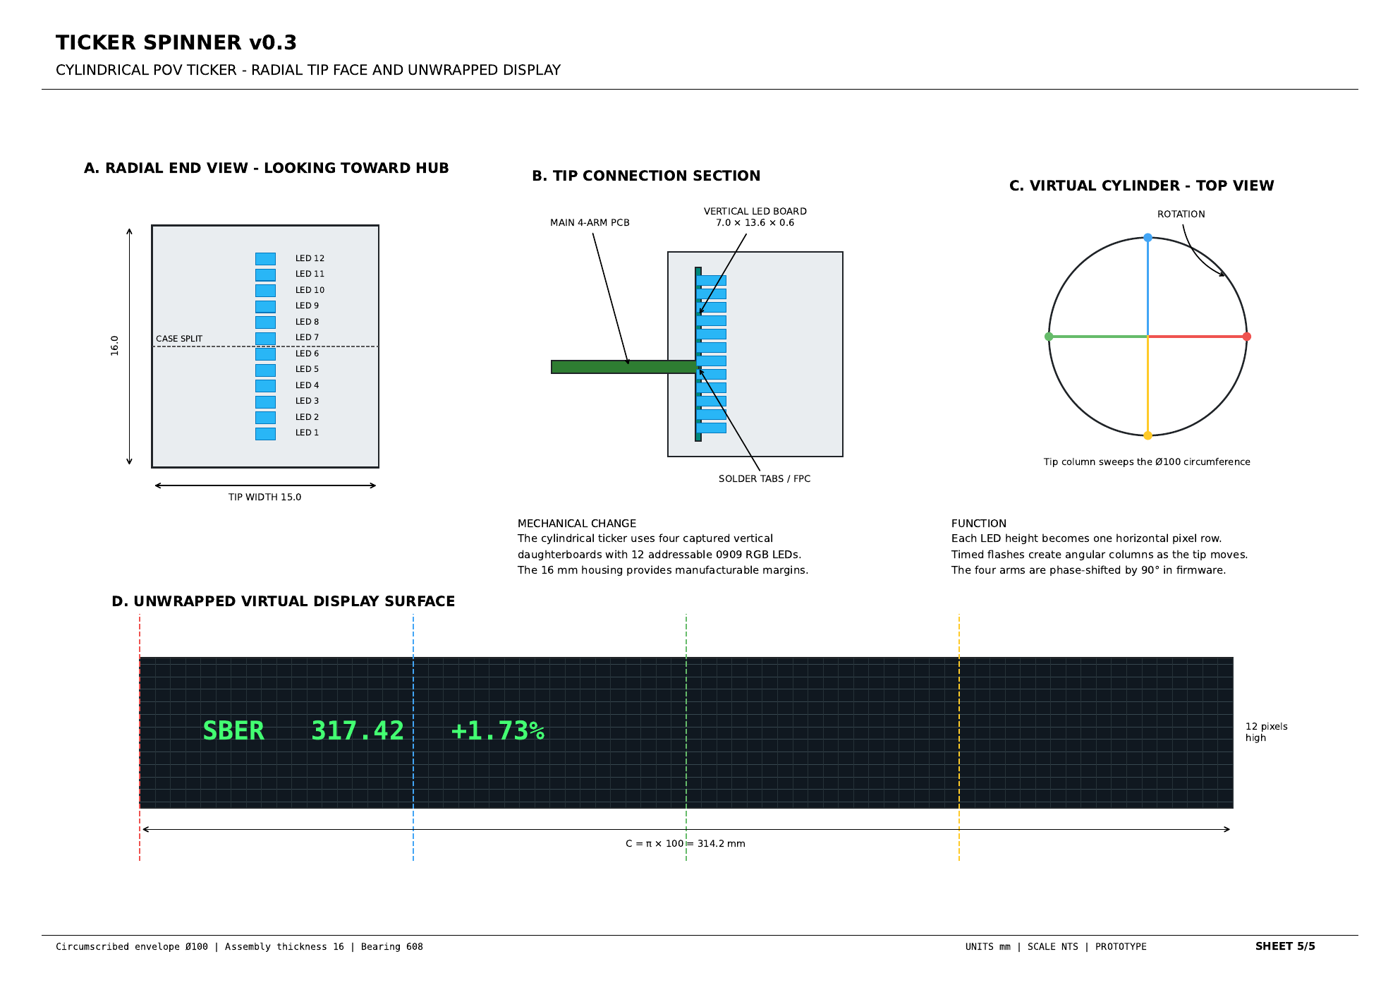
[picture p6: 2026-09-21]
public/assets/drawings/sheet-5.png

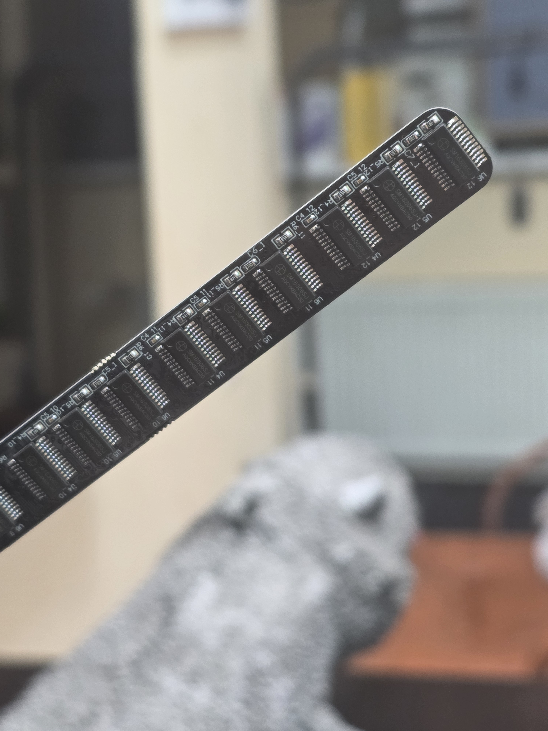
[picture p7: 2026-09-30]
public/assets/reference-fan/driver-sm16306sj.jpg

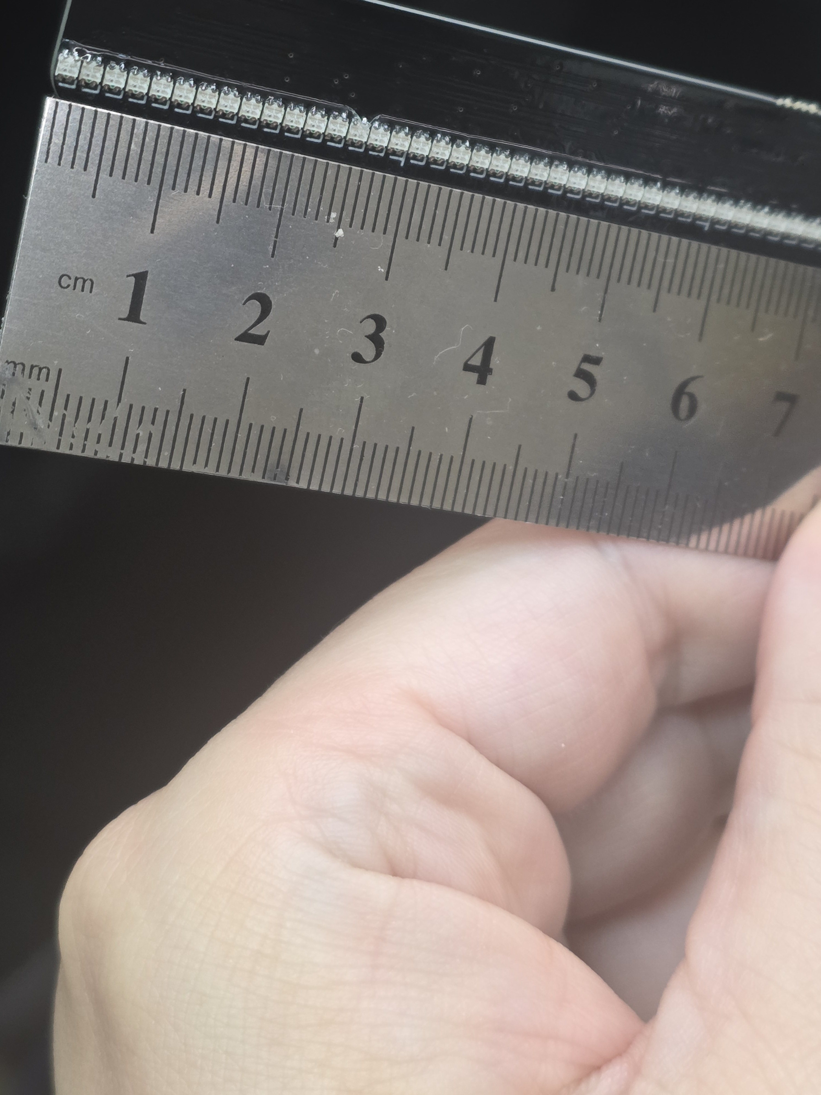
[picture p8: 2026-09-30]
public/assets/reference-fan/led-ruler.jpg

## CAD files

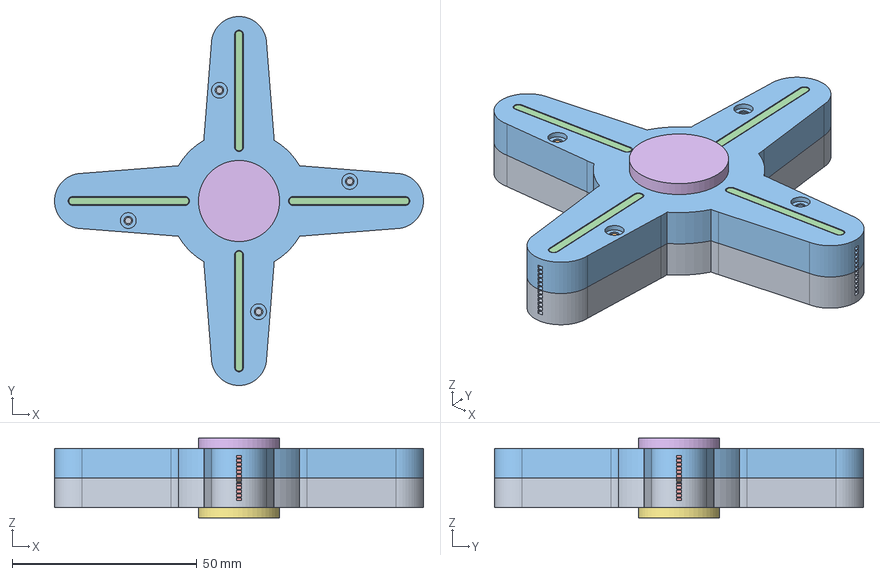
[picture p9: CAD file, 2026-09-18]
public/project-files/ticker_spinner_v0_3_assembly.step
100.0 x 100.0 x 21.6 mm

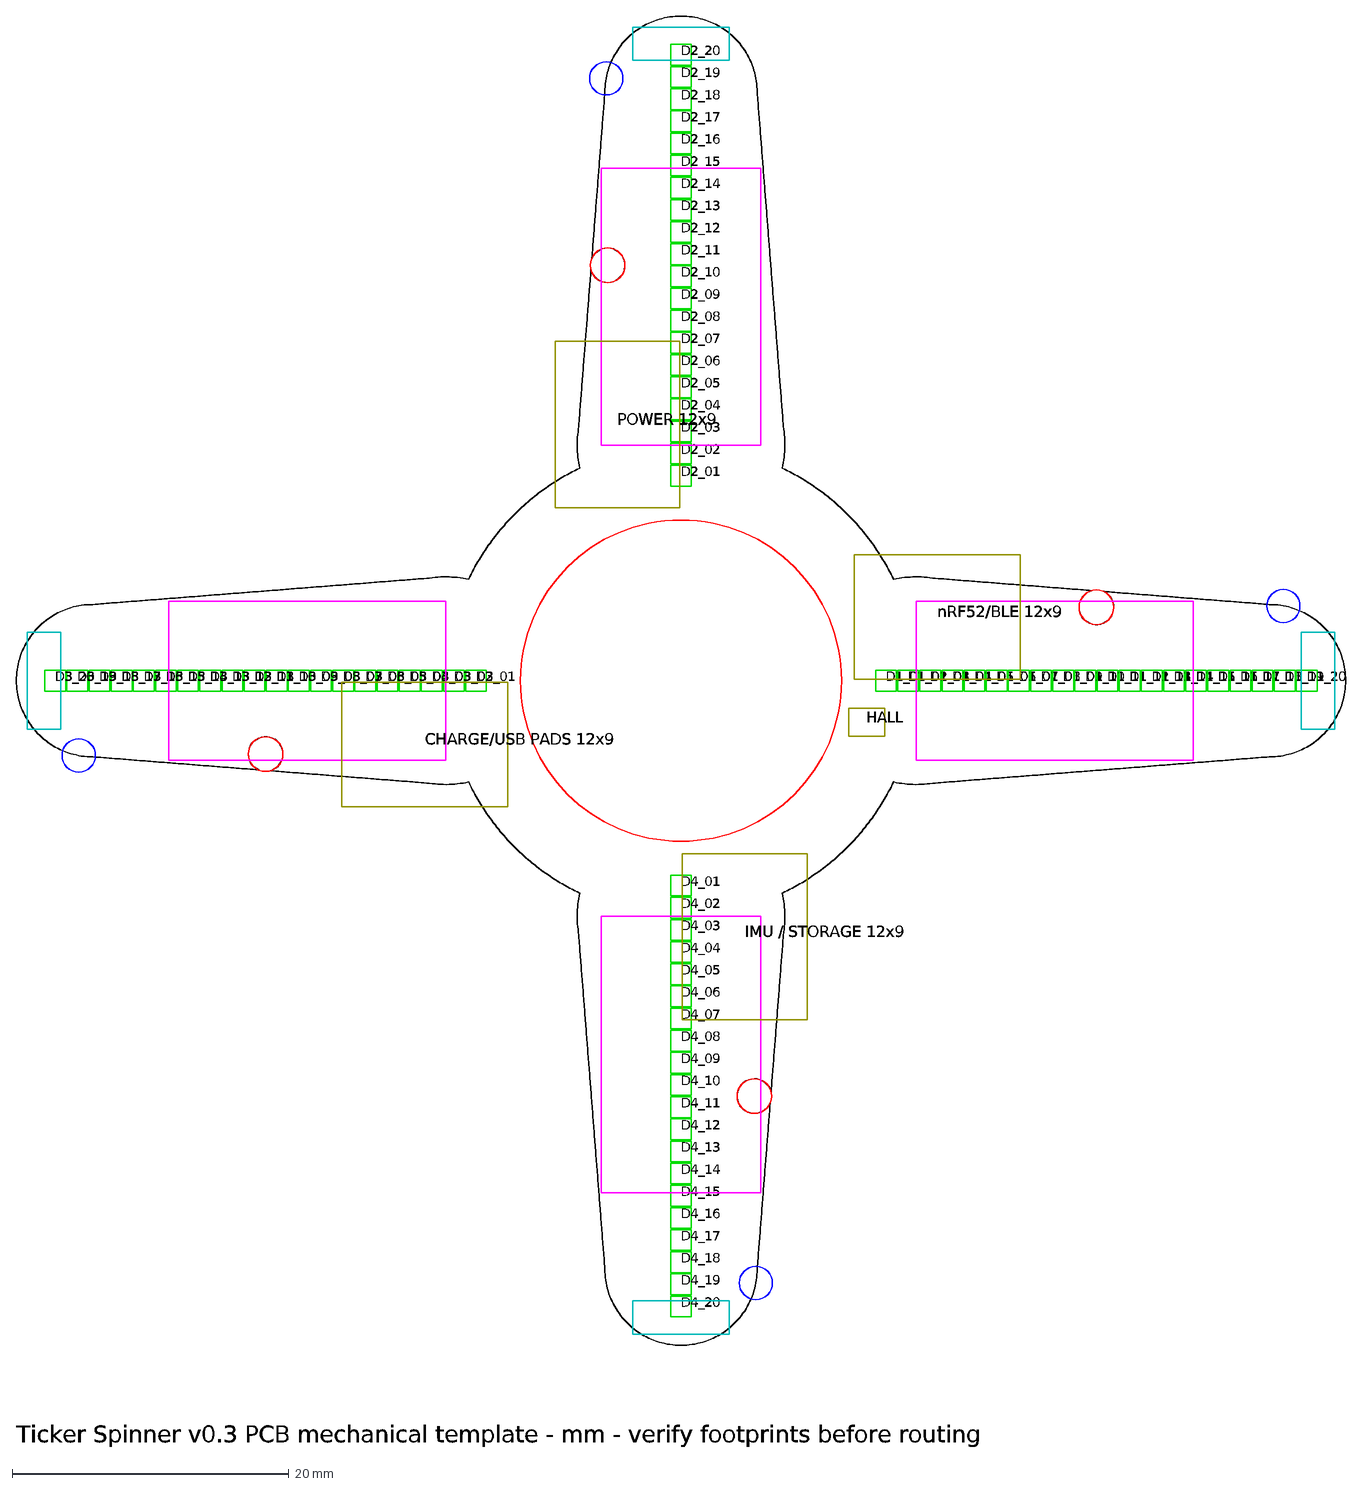
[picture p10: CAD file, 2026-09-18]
public/project-files/ticker_spinner_v0_3_pcb_outline.dxf
D1_01
D1_02
D1_03
D1_04
D1_05
D1_06
D1_07
D1_08
D1_09
D1_10
D1_11
D1_12
D1_13
D1_14
D1_15
D1_16
D1_17
D1_18
D1_19
D1_20
D2_01
D2_02
D2_03
D2_04
D2_05
D2_06
D2_07
D2_08
D2_09
D2_10
D2_11
D2_12
D2_13
D2_14
D2_15
D2_16
D2_17
D2_18
D2_19
D2_20
D3_01
D3_02
D3_03
D3_04
D3_05
D3_06
D3_07
D3_08
D3_09
D3_10
D3_11
D3_12
D3_13
D3_14
D3_15
D3_16
D3_17
D3_18
D3_19
D3_20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

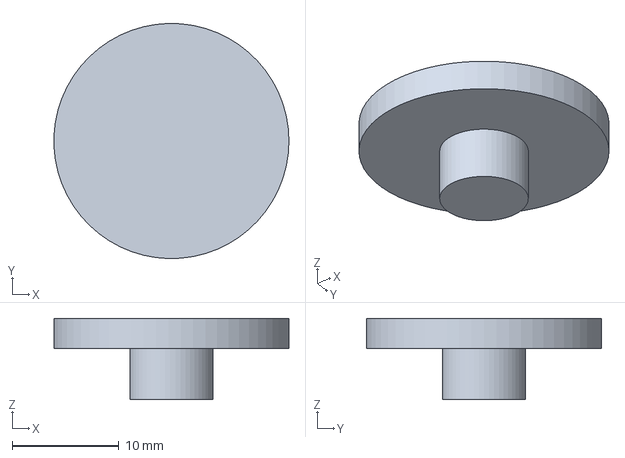
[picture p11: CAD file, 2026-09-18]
public/project-files/ticker_spinner_v0_3_finger_cap_top.step
22.0 x 22.0 x 7.60 mm

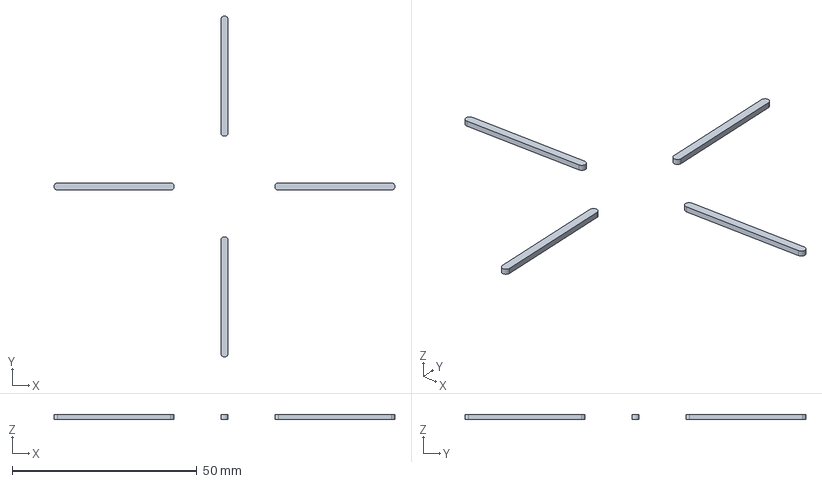
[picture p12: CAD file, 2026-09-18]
public/project-files/ticker_spinner_v0_3_diffusers.step
92.2 x 92.2 x 1.25 mm

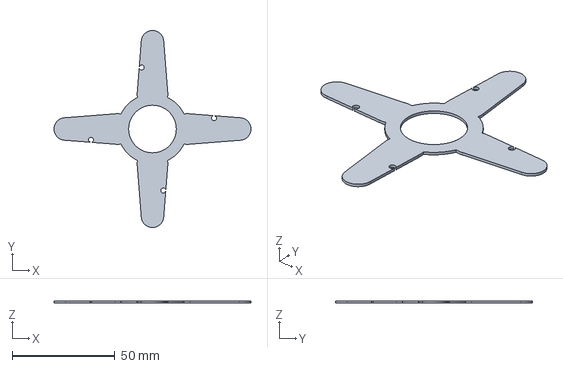
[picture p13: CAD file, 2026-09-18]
public/project-files/ticker_spinner_v0_3_pcb_envelope.step
96.0 x 96.0 x 1.00 mm

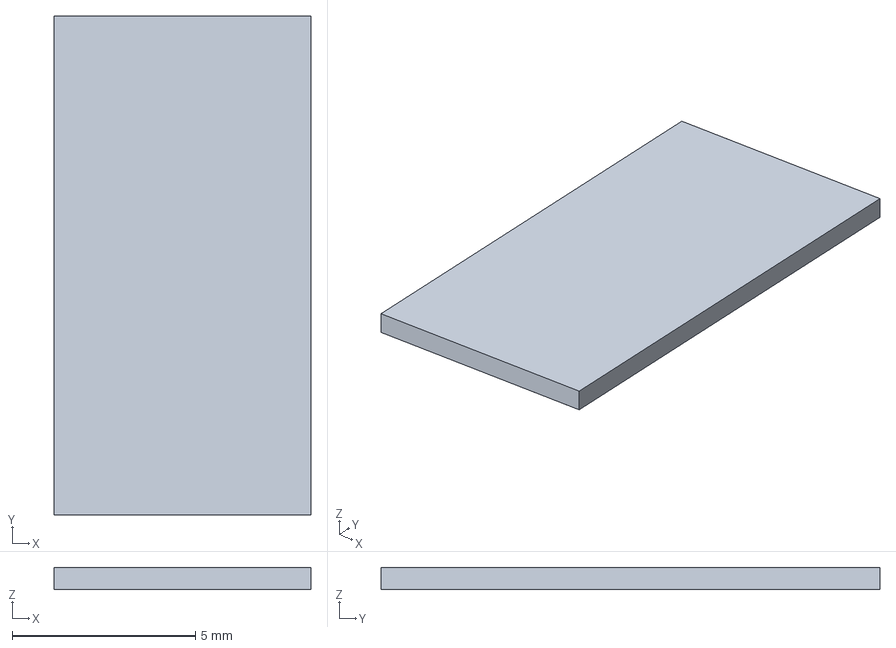
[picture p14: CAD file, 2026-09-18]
public/project-files/ticker_spinner_v0_3_tip_led_board_envelope.step
7.00 x 13.6 x 0.6 mm

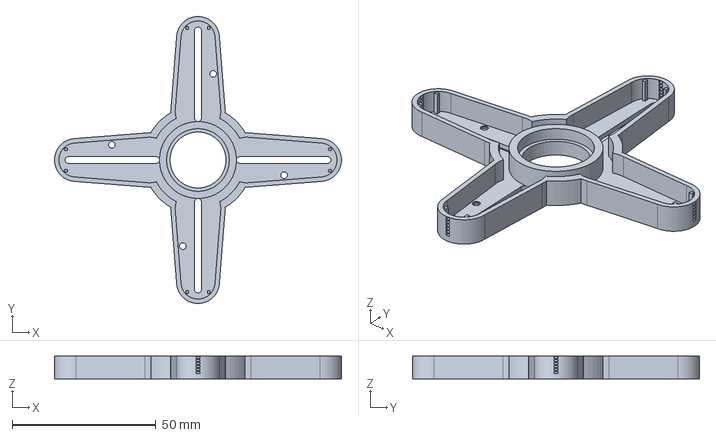
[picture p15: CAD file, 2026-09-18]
public/project-files/ticker_spinner_v0_3_top.step
100.0 x 100.0 x 8.00 mm

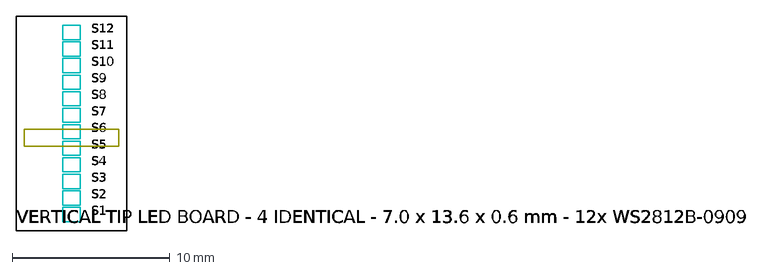
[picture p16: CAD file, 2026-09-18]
public/project-files/ticker_spinner_v0_3_tip_led_board.dxf
S1
S2
S3
S4
S5
S6
S7
S8
S9
S10
S11
S12
VERTICAL TIP LED BOARD - 4 IDENTICAL - 7.0 x 13.6 x 0.6 mm - 12x WS2812B-0909

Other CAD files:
public/project-files/ticker_spinner_v0_3_finger_cap_bottom.step
public/project-files/ticker_spinner_v0_3_bottom.step
public/project-files/ticker_spinner_v0_3_bottom.stl
public/project-files/ticker_spinner_v0_3_diffusers.stl
public/project-files/ticker_spinner_v0_3_finger_cap_bottom.stl
public/project-files/ticker_spinner_v0_3_finger_cap_top.stl
public/project-files/ticker_spinner_v0_3_pcb_envelope.stl
public/project-files/ticker_spinner_v0_3_tip_led_board_envelope.stl
public/project-files/ticker_spinner_v0_3_top.stl

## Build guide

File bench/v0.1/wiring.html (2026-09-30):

# SmartSpinner B0.1: монтажная таблица

Неподвижный стенд. На железе не проверено. Все узлы одной именованной сети электрически соединены. Номера выводов корпуса, не случайные номера переходника. Не соединять +5V_LOGIC и +5V_LED.

Инструкция PDF · Исходный список сетей

Схема питания и управления

## 96 цветовых каналов

LED / PIX | Банк | R: pin1 | G: pin4 | B: pin3
D1 / 0 | TOP | U1.5 (CH 0) | U1.6 (CH 1) | U1.7 (CH 2)
D2 / 1 | TOP | U1.8 (CH 3) | U1.9 (CH 4) | U1.10 (CH 5)
D3 / 2 | TOP | U1.11 (CH 6) | U1.12 (CH 7) | U1.13 (CH 8)
D4 / 3 | TOP | U1.14 (CH 9) | U1.15 (CH 10) | U1.16 (CH 11)
D5 / 4 | TOP | U1.17 (CH 12) | U1.18 (CH 13) | U1.19 (CH 14)
D6 / 5 | TOP | U1.20 (CH 15) | U2.5 (CH 16) | U2.6 (CH 17)
D7 / 6 | TOP | U2.7 (CH 18) | U2.8 (CH 19) | U2.9 (CH 20)
D8 / 7 | TOP | U2.10 (CH 21) | U2.11 (CH 22) | U2.12 (CH 23)
D9 / 8 | TOP | U2.13 (CH 24) | U2.14 (CH 25) | U2.15 (CH 26)
D10 / 9 | TOP | U2.16 (CH 27) | U2.17 (CH 28) | U2.18 (CH 29)
D11 / 10 | TOP | U2.19 (CH 30) | U2.20 (CH 31) | U3.5 (CH 32)
D12 / 11 | TOP | U3.6 (CH 33) | U3.7 (CH 34) | U3.8 (CH 35)
D13 / 12 | TOP | U3.9 (CH 36) | U3.10 (CH 37) | U3.11 (CH 38)
D14 / 13 | TOP | U3.12 (CH 39) | U3.13 (CH 40) | U3.14 (CH 41)
D15 / 14 | TOP | U3.15 (CH 42) | U3.16 (CH 43) | U3.17 (CH 44)
D16 / 15 | TOP | U3.18 (CH 45) | U3.19 (CH 46) | U3.20 (CH 47)
D17 / 16 | TOP | U4.5 (CH 48) | U4.6 (CH 49) | U4.7 (CH 50)
D18 / 17 | TOP | U4.8 (CH 51) | U4.9 (CH 52) | U4.10 (CH 53)
D19 / 18 | TOP | U4.11 (CH 54) | U4.12 (CH 55) | U4.13 (CH 56)
D20 / 19 | TOP | U4.14 (CH 57) | U4.15 (CH 58) | U4.16 (CH 59)
D21 / 20 | TIP | U4.17 (CH 60) | U4.18 (CH 61) | U4.19 (CH 62)
D22 / 21 | TIP | U4.20 (CH 63) | U5.5 (CH 64) | U5.6 (CH 65)
D23 / 22 | TIP | U5.7 (CH 66) | U5.8 (CH 67) | U5.9 (CH 68)
D24 / 23 | TIP | U5.10 (CH 69) | U5.11 (CH 70) | U5.12 (CH 71)
D25 / 24 | TIP | U5.13 (CH 72) | U5.14 (CH 73) | U5.15 (CH 74)
D26 / 25 | TIP | U5.16 (CH 75) | U5.17 (CH 76) | U5.18 (CH 77)
D27 / 26 | TIP | U5.19 (CH 78) | U5.20 (CH 79) | U6.5 (CH 80)
D28 / 27 | TIP | U6.6 (CH 81) | U6.7 (CH 82) | U6.8 (CH 83)
D29 / 28 | TIP | U6.9 (CH 84) | U6.10 (CH 85) | U6.11 (CH 86)
D30 / 29 | TIP | U6.12 (CH 87) | U6.13 (CH 88) | U6.14 (CH 89)
D31 / 30 | TIP | U6.15 (CH 90) | U6.16 (CH 91) | U6.17 (CH 92)
D32 / 31 | TIP | U6.18 (CH 93) | U6.19 (CH 94) | U6.20 (CH 95)

## Все электрические сети

Сеть | Соединённые контакты
GND | U1.1, R1.2, C1.2, U2.1, R2.2, C2.2, U3.1, R3.2, C3.2, U4.1, R4.2, C4.2, U5.1, R5.2, C5.2, U6.1, R6.2, C6.2, A1.GND, PS1.-, C7.-, C8.-, C9.2, R12.2, TP_GND.1
+5V_LOGIC | U1.24, C1.1, U2.24, C2.1, U3.24, C3.1, U4.24, C4.1, U5.24, C5.1, U6.24, C6.1, A1.5V, S1.OFF, R11.1, C7.+, PD1.K, TP_LOGIC.1
REXT_1 | U1.23, R1.1
CLK_BUS | U1.3, U2.3, U3.3, U4.3, U5.3, U6.3, R8.2, TP_CLK.1
LE_BUS | U1.4, U2.4, U3.4, U4.4, U5.4, U6.4, R9.2, TP_LE.1
OE_BUS | U1.21, U2.21, U3.21, U4.21, U5.21, U6.21, S1.COM, R11.2, TP_OE.1
DATA_0 | U1.2, R7.2
REXT_2 | U2.23, R2.1
DATA_1 | U1.22, U2.2
REXT_3 | U3.23, R3.1
DATA_2 | U2.22, U3.2
REXT_4 | U4.23, R4.1
DATA_3 | U3.22, U4.2
REXT_5 | U5.23, R5.1
DATA_4 | U4.22, U5.2
REXT_6 | U6.23, R6.1
DATA_5 | U5.22, U6.2
DATA_6 | U6.22, TP_SDO.1
MOSI_RAW | A1.D11, R7.1
CLK_RAW | A1.D13, R8.1
LE_RAW | A1.D10, R9.1
OE_RAW | A1.D9, R10.1
OE_RUN | R10.2, S1.RUN
PSU_PLUS | PS1.+, F1.1
FUSED_PLUS | F1.2, S2.1
+5V_LED | S2.2, C8.+, C9.1, TP_LED.1, D1.2, D2.2, D3.2, D4.2, D5.2, D6.2, D7.2, D8.2, D9.2, D10.2, D11.2, D12.2, D13.2, D14.2, D15.2, D16.2, D17.2, D18.2, D19.2, D20.2, D21.2, D22.2, D23.2, D24.2, D25.2, D26.2, D27.2, D28.2, D29.2, D30.2, D31.2, D32.2
MARK | A1.D8, TP_MARK.1
LIGHT | PD1.A, R12.1, TP_LIGHT.1
CH_00_R | U1.5, D1.1
CH_01_G | U1.6, D1.4
CH_02_B | U1.7, D1.3
CH_03_R | U1.8, D2.1
CH_04_G | U1.9, D2.4
CH_05_B | U1.10, D2.3
CH_06_R | U1.11, D3.1
CH_07_G | U1.12, D3.4
CH_08_B | U1.13, D3.3
CH_09_R | U1.14, D4.1
CH_10_G | U1.15, D4.4
CH_11_B | U1.16, D4.3
CH_12_R | U1.17, D5.1
CH_13_G | U1.18, D5.4
CH_14_B | U1.19, D5.3
CH_15_R | U1.20, D6.1
CH_16_G | U2.5, D6.4
CH_17_B | U2.6, D6.3
CH_18_R | U2.7, D7.1
CH_19_G | U2.8, D7.4
CH_20_B | U2.9, D7.3
CH_21_R | U2.10, D8.1
CH_22_G | U2.11, D8.4
CH_23_B | U2.12, D8.3
CH_24_R | U2.13, D9.1
CH_25_G | U2.14, D9.4
CH_26_B | U2.15, D9.3
CH_27_R | U2.16, D10.1
CH_28_G | U2.17, D10.4
CH_29_B | U2.18, D10.3
CH_30_R | U2.19, D11.1
CH_31_G | U2.20, D11.4
CH_32_B | U3.5, D11.3
CH_33_R | U3.6, D12.1
CH_34_G | U3.7, D12.4
CH_35_B | U3.8, D12.3
CH_36_R | U3.9, D13.1
CH_37_G | U3.10, D13.4
CH_38_B | U3.11, D13.3
CH_39_R | U3.12, D14.1
CH_40_G | U3.13, D14.4
CH_41_B | U3.14, D14.3
CH_42_R | U3.15, D15.1
CH_43_G | U3.16, D15.4
CH_44_B | U3.17, D15.3
CH_45_R | U3.18, D16.1
CH_46_G | U3.19, D16.4
CH_47_B | U3.20, D16.3
CH_48_R | U4.5, D17.1
CH_49_G | U4.6, D17.4
CH_50_B | U4.7, D17.3
CH_51_R | U4.8, D18.1
CH_52_G | U4.9, D18.4
CH_53_B | U4.10, D18.3
CH_54_R | U4.11, D19.1
CH_55_G | U4.12, D19.4
CH_56_B | U4.13, D19.3
CH_57_R | U4.14, D20.1
CH_58_G | U4.15, D20.4
CH_59_B | U4.16, D20.3
CH_60_R | U4.17, D21.1
CH_61_G | U4.18, D21.4
CH_62_B | U4.19, D21.3
CH_63_R | U4.20, D22.1
CH_64_G | U5.5, D22.4
CH_65_B | U5.6, D22.3
CH_66_R | U5.7, D23.1
CH_67_G | U5.8, D23.4
CH_68_B | U5.9, D23.3
CH_69_R | U5.10, D24.1
CH_70_G | U5.11, D24.4
CH_71_B | U5.12, D24.3
CH_72_R | U5.13, D25.1
CH_73_G | U5.14, D25.4
CH_74_B | U5.15, D25.3
CH_75_R | U5.16, D26.1
CH_76_G | U5.17, D26.4
CH_77_B | U5.18, D26.3
CH_78_R | U5.19, D27.1
CH_79_G | U5.20, D27.4
CH_80_B | U6.5, D27.3
CH_81_R | U6.6, D28.1
CH_82_G | U6.7, D28.4
CH_83_B | U6.8, D28.3
CH_84_R | U6.9, D29.1
CH_85_G | U6.10, D29.4
CH_86_B | U6.11, D29.3
CH_87_R | U6.12, D30.1
CH_88_G | U6.13, D30.4
CH_89_B | U6.14, D30.3
CH_90_R | U6.15, D31.1
CH_91_G | U6.16, D31.4
CH_92_B | U6.17, D31.3
CH_93_R | U6.18, D32.1
CH_94_G | U6.19, D32.4
CH_95_B | U6.20, D32.3

## Обозначения компонентов

Ref | Компонент
A1 | Arduino UNO R3 5V 16MHz ATmega328P
PS1 | Isolated bench PSU 5.00V, current limit up to 0.60A
U1 | SM16306SJ QSOP24
R1 | 3.74k 1% 0.25W
C1 | 100nF X7R 16V
U2 | SM16306SJ QSOP24
R2 | 3.74k 1% 0.25W
C2 | 100nF X7R 16V
U3 | SM16306SJ QSOP24
R3 | 3.74k 1% 0.25W
C3 | 100nF X7R 16V
U4 | SM16306SJ QSOP24
R4 | 3.74k 1% 0.25W
C4 | 100nF X7R 16V
U5 | SM16306SJ QSOP24
R5 | 3.74k 1% 0.25W
C5 | 100nF X7R 16V
U6 | SM16306SJ QSOP24
R6 | 3.74k 1% 0.25W
C6 | 100nF X7R 16V
R7 | 47R
R8 | 47R
R9 | 47R
R10 | 100R
R11 | 10k
R12 | 10k
C7 | 10uF >=10V polarized
C8 | 100uF >=10V polarized
C9 | 100nF X7R 16V
S1 | SPDT BBM OFF/RUN
S2 | SPST power
F1 | 0.75A DC-rated fuse
PD1 | Vishay BPW34 optional
D1 | Kingbright WP154A4SEJ3VBDZGW/CA
D2 | Kingbright WP154A4SEJ3VBDZGW/CA
D3 | Kingbright WP154A4SEJ3VBDZGW/CA
D4 | Kingbright WP154A4SEJ3VBDZGW/CA
D5 | Kingbright WP154A4SEJ3VBDZGW/CA
D6 | Kingbright WP154A4SEJ3VBDZGW/CA
D7 | Kingbright WP154A4SEJ3VBDZGW/CA
D8 | Kingbright WP154A4SEJ3VBDZGW/CA
D9 | Kingbright WP154A4SEJ3VBDZGW/CA
D10 | Kingbright WP154A4SEJ3VBDZGW/CA
D11 | Kingbright WP154A4SEJ3VBDZGW/CA
D12 | Kingbright WP154A4SEJ3VBDZGW/CA
D13 | Kingbright WP154A4SEJ3VBDZGW/CA
D14 | Kingbright WP154A4SEJ3VBDZGW/CA
D15 | Kingbright WP154A4SEJ3VBDZGW/CA
D16 | Kingbright WP154A4SEJ3VBDZGW/CA
D17 | Kingbright WP154A4SEJ3VBDZGW/CA
D18 | Kingbright WP154A4SEJ3VBDZGW/CA
D19 | Kingbright WP154A4SEJ3VBDZGW/CA
D20 | Kingbright WP154A4SEJ3VBDZGW/CA
D21 | Kingbright WP154A4SEJ3VBDZGW/CA
D22 | Kingbright WP154A4SEJ3VBDZGW/CA
D23 | Kingbright WP154A4SEJ3VBDZGW/CA
D24 | Kingbright WP154A4SEJ3VBDZGW/CA
D25 | Kingbright WP154A4SEJ3VBDZGW/CA
D26 | Kingbright WP154A4SEJ3VBDZGW/CA
D27 | Kingbright WP154A4SEJ3VBDZGW/CA
D28 | Kingbright WP154A4SEJ3VBDZGW/CA
D29 | Kingbright WP154A4SEJ3VBDZGW/CA
D30 | Kingbright WP154A4SEJ3VBDZGW/CA
D31 | Kingbright WP154A4SEJ3VBDZGW/CA
D32 | Kingbright WP154A4SEJ3VBDZGW/CA

R13 1k - возможная замена R12, не дополнительный параллельный резистор. R14 470R - отдельный тест LED до монтажа; в основной сети его нет. PD1/R12 необязательны для статического запуска.

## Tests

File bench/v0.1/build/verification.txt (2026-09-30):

SmartSpinner B0.1 software verification
Timestamp: 2026-09-29T20:41:52.415518+00:00
HARDWARE TESTS: NOT PERFORMED. No motor, battery or PCB production qualification.
$ arduino-cli version
arduino-cli  Version: 1.5.1 Commit: Homebrew Date: 2026-06-05T09:39:33Z

Exit: 0
$ arduino-cli core list
ID          Installed Latest Name
arduino:avr 1.8.8     1.8.8  Arduino AVR Boards
esp32:esp32 3.3.11    3.3.11 esp32

Exit: 0
$ arduino-cli compile --fqbn arduino:avr:uno --output-dir build/uno firmware/spinner_bench
Sketch uses 4712 bytes (14%) of program storage space. Maximum is 32256 bytes.
Global variables use 334 bytes (16%) of dynamic memory, leaving 1714 bytes for local variables. Maximum is 2048 bytes.

Exit: 0
$ c++ -std=c++11 -Wall -Wextra -Werror tests/test_core.cpp -o /var/folders/p2/l0jzx4cs1jz6z1tv69qvvfjh0000gn/T/spinner-bench-test-kvj2ngw1/test_core

Exit: 0
$ /var/folders/p2/l0jzx4cs1jz6z1tv69qvvfjh0000gn/T/spinner-bench-test-kvj2ngw1/test_core
PASS: 96 independent shift-chain cases; 256 RGB masks; bounds and parser cases

Exit: 0
$ /Users/germanklimenko/.cache/codex-runtimes/codex-primary-runtime/dependencies/python/bin/python3 tools/verify_wiring.py
PASS: 341 nodes; all 144 driver pins accounted for; 96 unique LED channels
PASS: separate positive rails, shared ground, OE switch, R_EXT and decoupling, LED polarity
LIMIT: static connection checks only; no analog simulation, hardware measurements or KiCad ERC

Exit: 0

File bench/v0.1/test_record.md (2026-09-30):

# Протокол B0.1 - НЕ ПРОВЕДЕНО

Дата / сборщик / фото монтажа:
Фактические MPN и партия U / D:
UNO и версия загруженной прошивки:
Приборы, погрешность, щупы, частота дискретизации:

| Тест | Фактическое измерение / файл осциллограммы | PASS / FAIL / НЕ ПРОВЕДЕНО |
| --- | --- | --- |
| G0 MPN и корпуса | | НЕ ПРОВЕДЕНО |
| G1 монтаж/прозвонка/R_EXT | | НЕ ПРОВЕДЕНО |
| T01 питания и OE | | НЕ ПРОВЕДЕНО |
| T02 запрет/Reset, ток OFF | | НЕ ПРОВЕДЕНО |
| T03 ток R/G/B D1 | | НЕ ПРОВЕДЕНО |
| T04 все 96 каналов | | НЕ ПРОВЕДЕНО |
| T05 ток/напряжение ALL | | НЕ ПРОВЕДЕНО |
| T06 тайм-ауты/S1 | | НЕ ПРОВЕДЕНО |
| T07 SPI 125k/1M/4M | | НЕ ПРОВЕДЕНО |
| T08 свет 20/50/100 мкс | | НЕ ПРОВЕДЕНО |
| Температура U1...U6 до/после | | НЕ ПРОВЕДЕНО |

Для T08: R нагрузки фотодиода, расстояние, ширина MARK/света min/mean/max, задержка, число выборок, отсутствие насыщения. Не обозначать микросекундную точность без достаточного прибора.

Дефекты и исправления:
Повторно выполненные тесты:
Решение по следующему прототипу (не разрешение на вращение):

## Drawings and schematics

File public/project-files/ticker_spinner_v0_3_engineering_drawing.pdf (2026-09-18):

## A. TOP VIEW

## B. SIDE ELEVATION

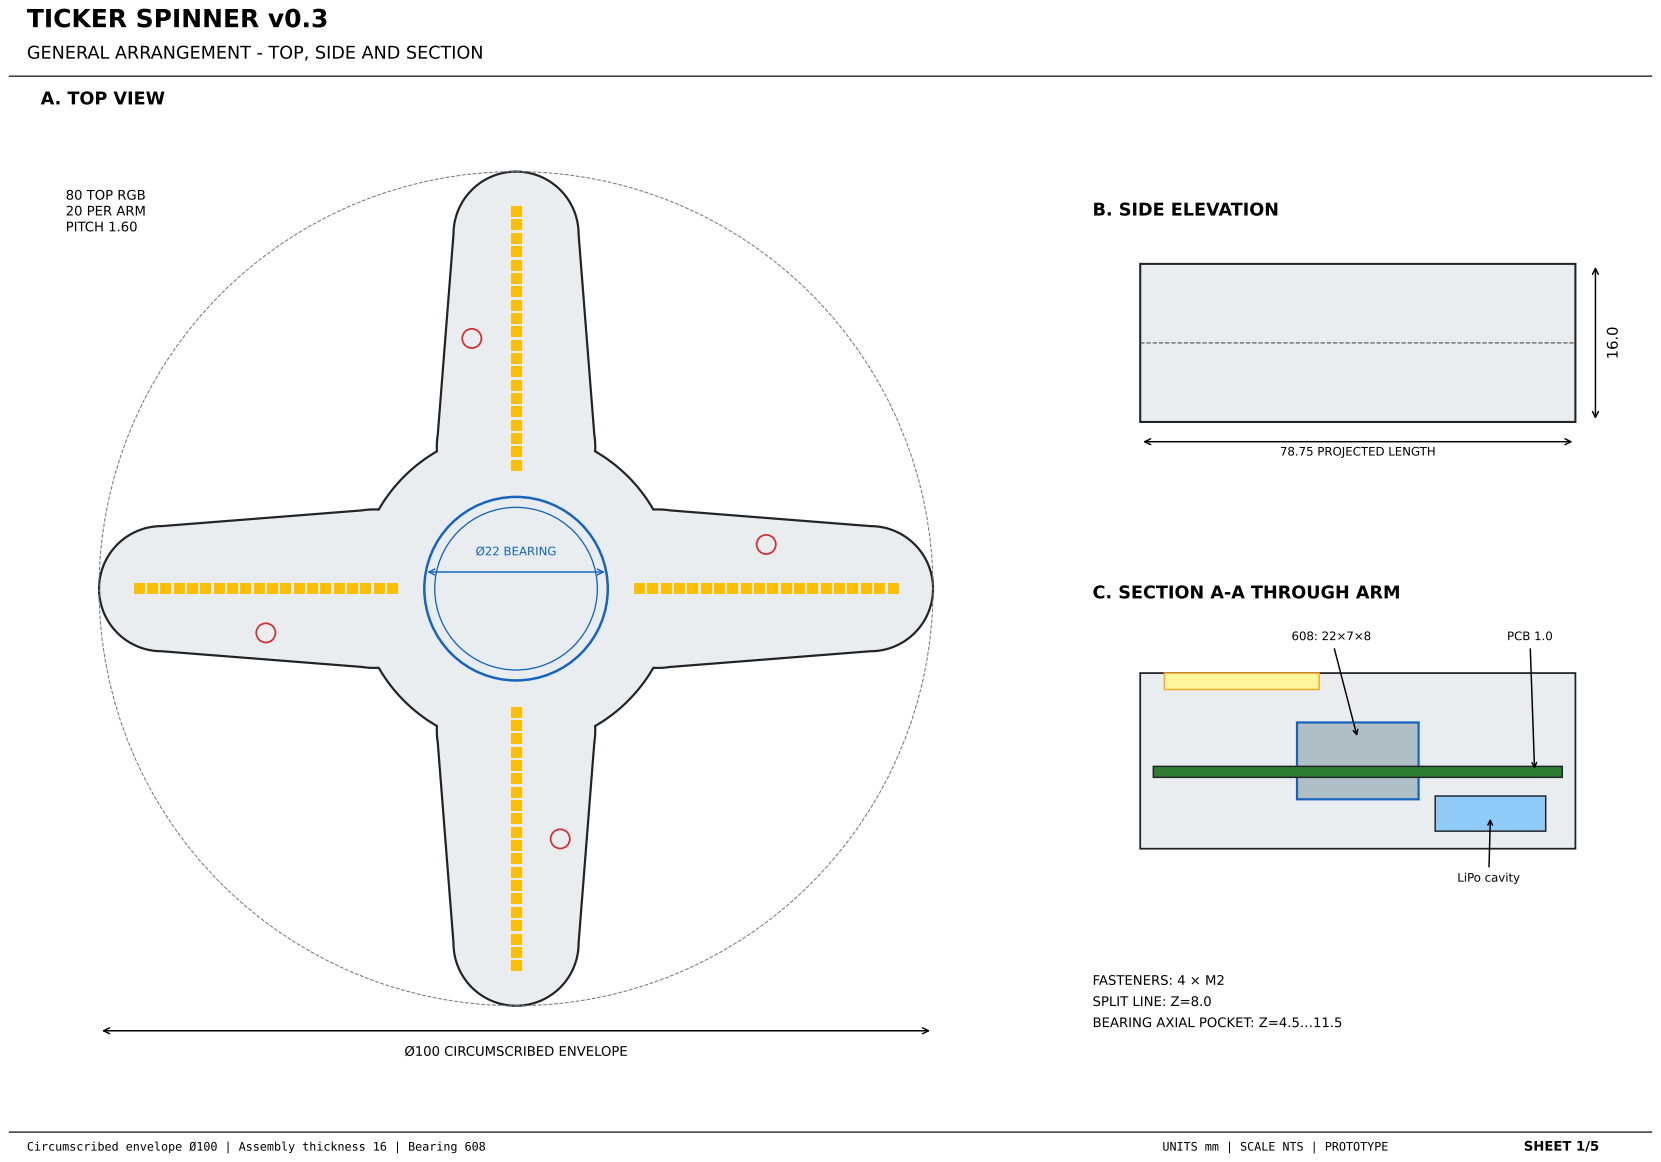
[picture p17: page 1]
Ø100 CIRCUMSCRIBED ENVELOPE; Ø22 BEARING; 80 TOP RGB 20 PER ARM PITCH 1.60; 78.75 PROJECTED LENGTH; PCB 1.0; LiPo cavity; TICKER SPINNER v0.3; Circumscribed envelope Ø100 | Assembly thickness 16 | Bearing 608; UNITS mm | SCALE NTS | PROTOTYPE; SHEET 1/5

GENERAL ARRANGEMENT - TOP, SIDE AND SECTION

C. SECTION A-A THROUGH ARM

FASTENERS: 4 × M2
SPLIT LINE: Z=8.0
BEARING AXIAL POCKET: Z=4.5…11.5

## A. VIEW FROM INSIDE

## B. BEARING RETENTION SECTION

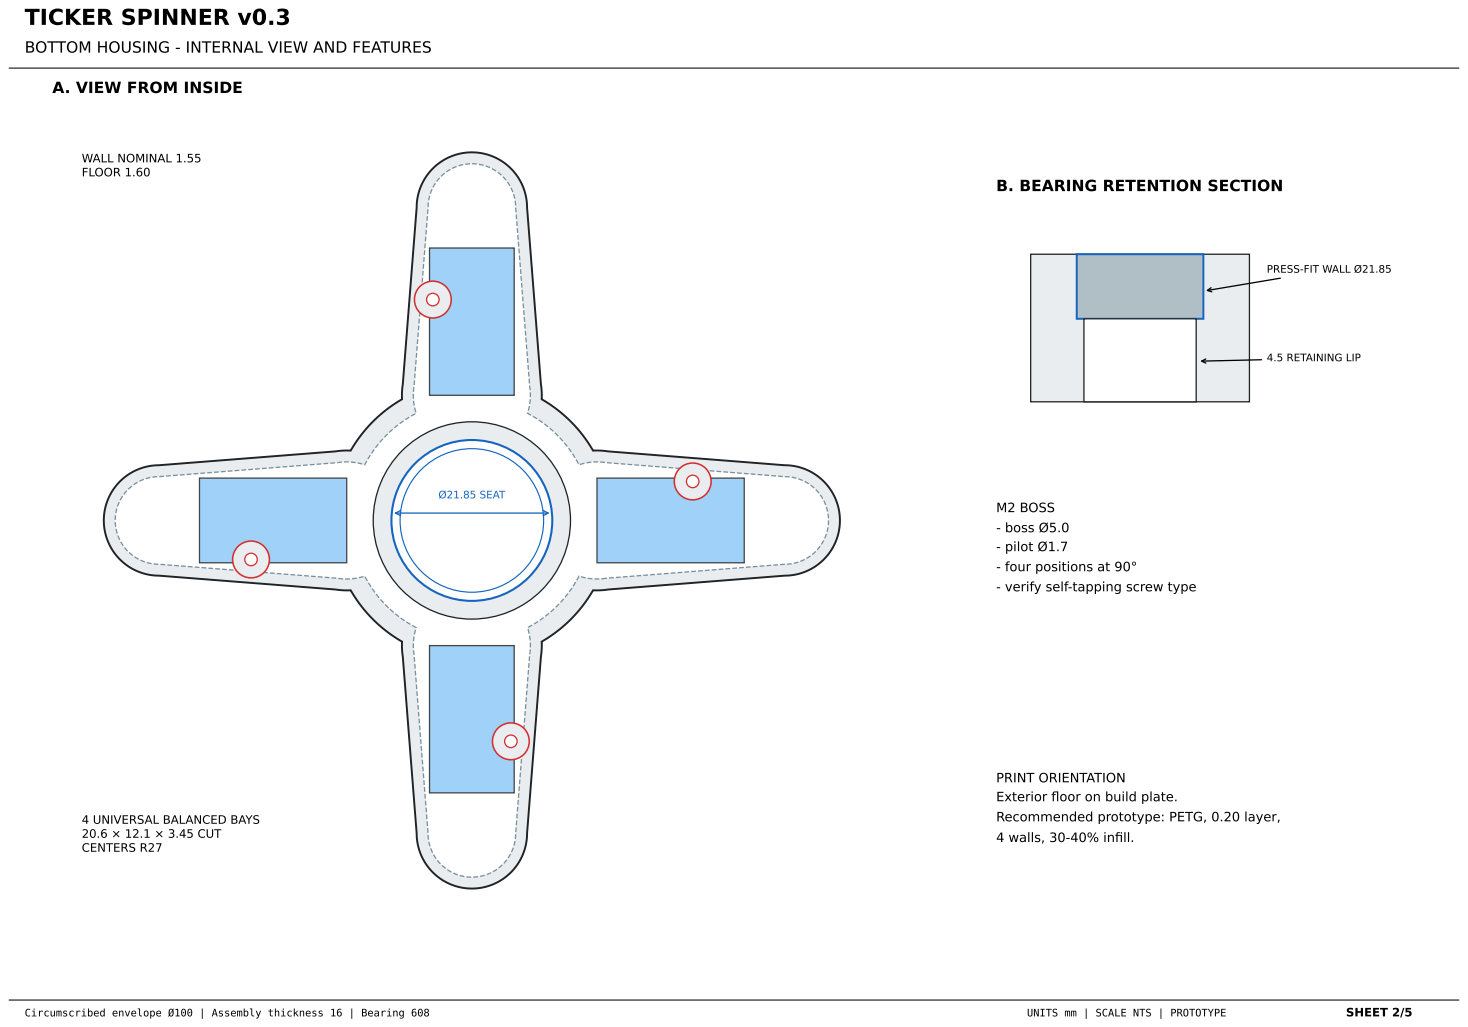
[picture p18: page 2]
WALL NOMINAL 1.55 FLOOR 1.60; Ø21.85 SEAT; 4.5 RETAINING LIP; Circumscribed envelope Ø100 | Assembly thickness 16 | Bearing 608; UNITS mm | SCALE NTS | PROTOTYPE; SHEET 2/5

BOTTOM HOUSING - INTERNAL VIEW AND FEATURES

PRESS-FIT WALL Ø21.85

M2 BOSS
- boss Ø5.0
- pilot Ø1.7
- four positions at 90°
- verify self-tapping screw type

PRINT ORIENTATION
Exterior floor on build plate.

Recommended prototype: PETG, 0.20 layer,
4 walls, 30-40% infill.

4 UNIVERSAL BALANCED BAYS
20.6 × 12.1 × 3.45 CUT
CENTERS R27

## A. EXTERNAL VIEW

## B. UNDERSIDE VIEW

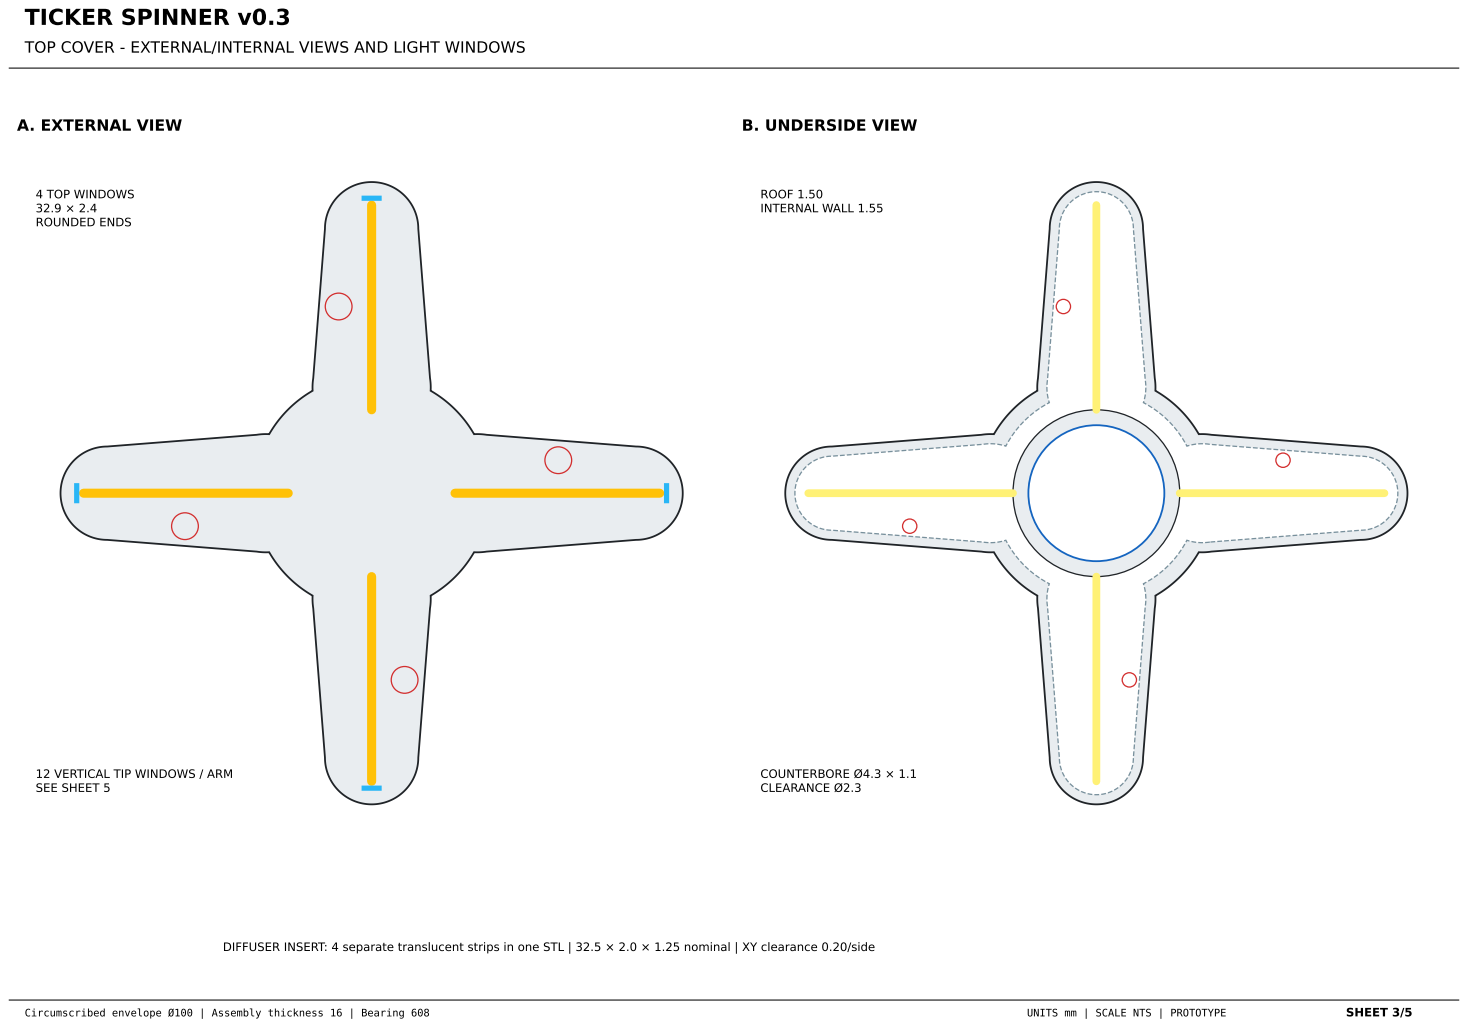
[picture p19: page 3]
4 TOP WINDOWS 32.9 × 2.4 ROUNDED ENDS; ROOF 1.50 INTERNAL WALL 1.55; COUNTERBORE Ø4.3 × 1.1 CLEARANCE Ø2.3; Circumscribed envelope Ø100 | Assembly thickness 16 | Bearing 608; UNITS mm | SCALE NTS | PROTOTYPE; SHEET 3/5

TOP COVER - EXTERNAL/INTERNAL VIEWS AND LIGHT WINDOWS

12 VERTICAL TIP WINDOWS / ARM
SEE SHEET 5

DIFFUSER INSERT: 4 separate translucent strips in one STL | 32.5 × 2.0 × 1.25 nominal | XY clearance 0.20/side

## A. PCB TOP / COMPONENT SIDE

## LEGEND / ROUTING BASIS

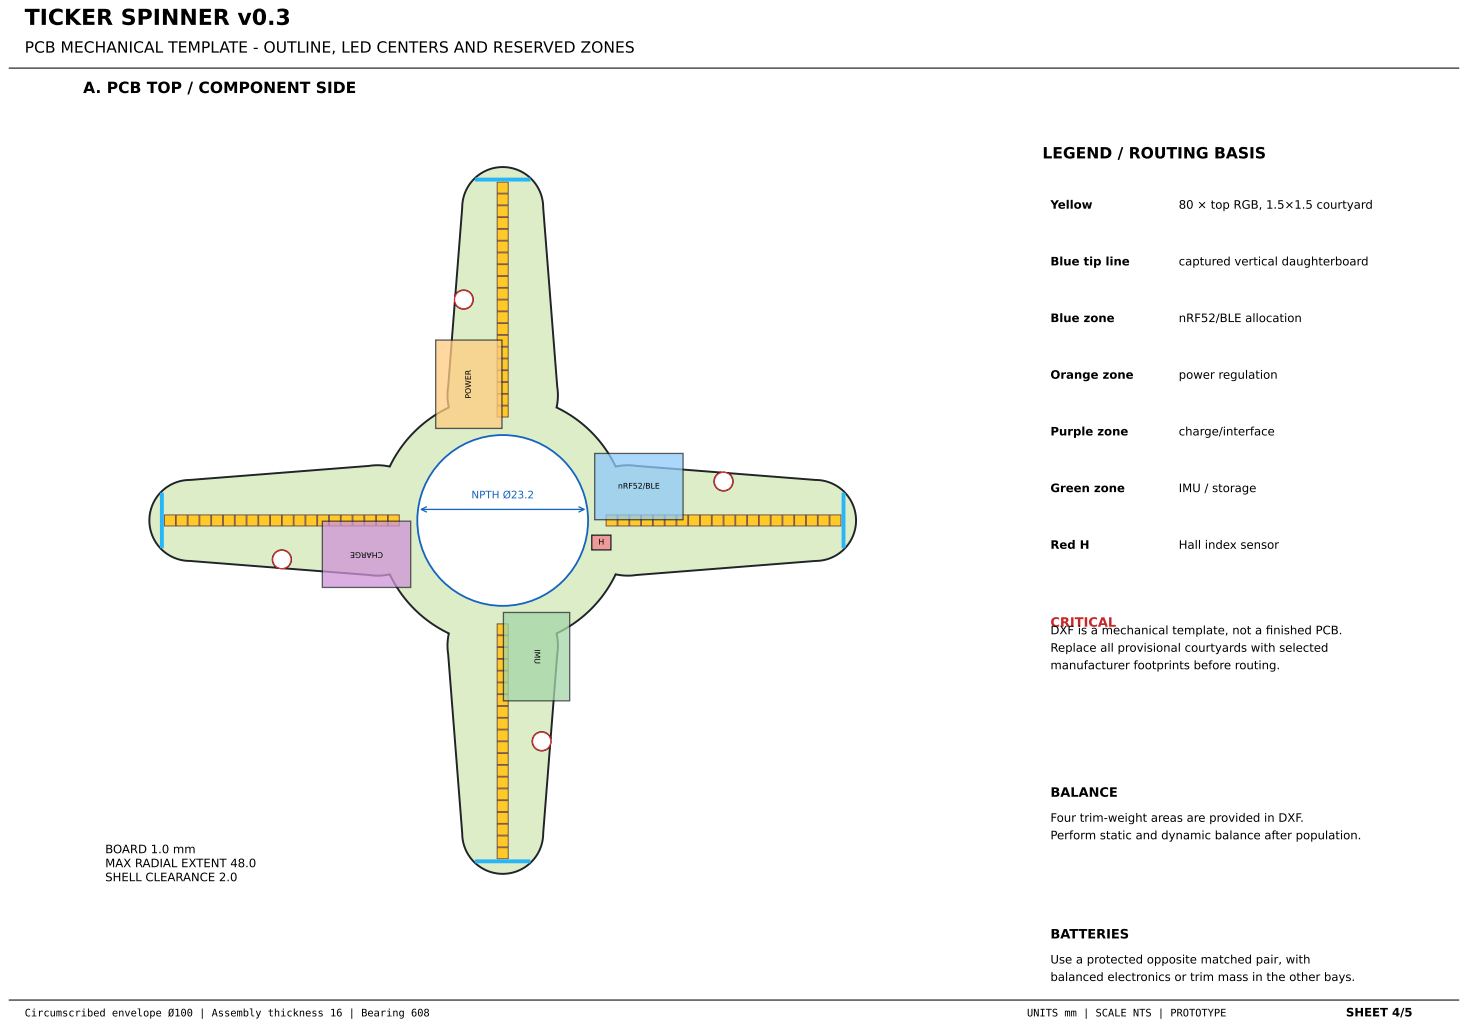
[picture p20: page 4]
nRF52/BLE; POWER; IMU; NPTH Ø23.2; Yellow; 80 × top RGB, 1.5×1.5 courtyard; Blue tip line; captured vertical daughterboard; Blue zone; nRF52/BLE allocation; Orange zone; power regulation; Purple zone; charge/interface; Green zone; IMU / storage; Red H; Hall index sensor; BALANCE; BATTERIES; Circumscribed envelope Ø100 | Assembly thickness 16 | Bearing 608; UNITS mm | SCALE NTS | PROTOTYPE; SHEET 4/5

PCB MECHANICAL TEMPLATE - OUTLINE, LED CENTERS AND RESERVED ZONES

CRITICAL DXF is a mechanical template, not a finished PCB.

Replace all provisional courtyards with selected
manufacturer footprints before routing.

Four trim-weight areas are provided in DXF.
Perform static and dynamic balance after population.

BOARD 1.0 mm
MAX RADIAL EXTENT 48.0
SHELL CLEARANCE 2.0

Use a protected opposite matched pair, with
balanced electronics or trim mass in the other bays.

LED 1

LED 2

LED 3

LED 4

LED 5

LED 6

LED 7

LED 8

LED 9

LED 10

LED 11

LED 12

16.0

TIP WIDTH 15.0

CASE SPLIT

## A. RADIAL END VIEW - LOOKING TOWARD HUB

VERTICAL LED BOARD
MAIN 4-ARM PCB | 7.0 × 13.6 × 0.6

SOLDER TABS / FPC

## B. TIP CONNECTION SECTION

ROTATION

Tip column sweeps the Ø100 circumference

## C. VIRTUAL CYLINDER - TOP VIEW

SBER | 317.42 | +1.73%
C = π × 100 | = 314.2 mm

12 pixels
high

## D. UNWRAPPED VIRTUAL DISPLAY SURFACE

## CYLINDRICAL POV TICKER - RADIAL TIP FACE AND UNWRAPPED DISPLAY

Circumscribed envelope Ø100 | Assembly thickness 16 | Bearing 608 | UNITS mm | SCALE NTS | PROTOTYPE | SHEET 5/5

FUNCTION
Each LED height becomes one horizontal pixel row. Timed flashes create angular columns as the tip moves. The four arms are phase-shifted by 90° in firmware.

MECHANICAL CHANGE
The cylindrical ticker uses four captured vertical daughterboards with 12 addressable 0909 RGB LEDs. The 16 mm housing provides manufacturable margins.

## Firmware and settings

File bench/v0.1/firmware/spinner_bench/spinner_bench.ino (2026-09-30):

/* SmartSpinner B0.1 - STATIONARY ONLY; UNO R3 / ATmega328P 16 MHz.
 * SM16306SJ x6, 32 common-anode RGB, R_EXT = 3.74 kohm.
 * No motor, battery, BLE, automatic brightness, or production POV firmware.
 * S1 physical OFF is mandatory. Timeout is NOT a hardware safety system.
 */
#include <SPI.h>
#include "bench_core.h"
#if !defined(__AVR_ATmega328P__) || F_CPU != 16000000UL
#error "This firmware requires the 5 V, 16 MHz UNO R3 ATmega328P"
#endif

const uint8_t LE = 10, OE = 9, MARK = 8;
bench::Frame frame;
uint32_t spiHz = 125000, started = 0, lifetime = 0, lastStep = 0, lastPulse = 0;
bench::Op mode = bench::OFF;
uint8_t walkChannel = 0;
uint16_t pulseWidth = 50;
char input[64];
uint8_t used = 0;
bool discardLine = false;

void blank() { digitalWrite(OE, HIGH); digitalWrite(MARK, LOW); }
void sendFrame() {
  blank();
  digitalWrite(LE, LOW);
  SPI.beginTransaction(SPISettings(spiHz, MSBFIRST, SPI_MODE0));
  for (uint8_t n = 0; n < 12; ++n) SPI.transfer(frame.wireByte(n));
  SPI.endTransaction();
  digitalWrite(LE, HIGH);
  delayMicroseconds(2);
  digitalWrite(LE, LOW);
}
void stopOutputs() {
  blank(); mode = bench::OFF; frame.clear(); sendFrame();
}
void showStatic() { digitalWrite(OE, LOW); }
void help() {
  Serial.println(F("B0.1 STATIONARY ONLY; S1 OFF before wiring/power changes."));
  Serial.println(F("OFF | HELP | CH 0..95 | PIX 0..31 0..7 | ALL 0..7"));
  Serial.println(F("WALK | PULSE channel width_us(20..500)"));
  Serial.println(F("SPEED 125000|250000|500000|1000000|2000000|4000000"));
  Serial.println(F("Mask: R=1 G=2 B=4 W=7. CH/PIX/PULSE: 5s; ALL: 0.5s."));
}
void execute(char *line) {
  stopOutputs();
  bench::Command c = bench::parse(line);
  switch (c.op) {
    case bench::INVALID: Serial.println(F("ERR; outputs OFF")); return;
    case bench::HELP: help(); return;
    case bench::OFF: Serial.println(F("OFF")); return;
    case bench::SPEED:
      spiHz = c.a; Serial.print(F("SPI Hz=")); Serial.println(spiHz); return;
    case bench::CH: frame.channel(c.a); lifetime = 5000; break;
    case bench::PIX: frame.pixel(c.a, c.b); lifetime = 5000; break;
    case bench::ALL:
      for (uint8_t p = 0; p < bench::PIXELS; ++p) frame.pixel(p, c.a);
      lifetime = 500; break;
    case bench::WALK:
      walkChannel = 0; frame.channel(0); lifetime = 20000; lastStep = millis(); break;
    case bench::PULSE:
      frame.channel(c.a); pulseWidth = c.b; lifetime = 5000; break;
    default: return;
  }
  sendFrame();
  started = millis(); lastPulse = micros(); mode = c.op;
  if (mode != bench::PULSE) showStatic();
  Serial.println(F("RUN; S1 must be RUN to enable light"));
}
void setup() {
  // Set output latch BEFORE switching the pin to output.
  digitalWrite(OE, HIGH); pinMode(OE, OUTPUT);
  digitalWrite(MARK, LOW); pinMode(MARK, OUTPUT);
  digitalWrite(LE, LOW); pinMode(LE, OUTPUT); // SS output keeps AVR SPI master
  SPI.begin(); stopOutputs(); Serial.begin(115200); help();
}
void loop() {
  // Bound serial work so a continuously sending host cannot starve the timeout.
  for (uint8_t n = 0; n < 16 && Serial.available(); ++n) {
    char ch = Serial.read();
    if (ch == '\r') continue;
    if (ch == '\n') {
      if (!discardLine && used) { input[used] = 0; execute(input); }
      used = 0; discardLine = false;
    } else if (!discardLine) {
      if (used < sizeof(input) - 1) input[used++] = ch;
      else { discardLine = true; used = 0; stopOutputs(); }
    }
  }
  if (mode == bench::OFF) return;
  uint32_t now = millis();
  if (uint32_t(now - started) >= lifetime) {
    stopOutputs(); Serial.println(F("TIMEOUT; OFF")); return;
  }
  if (mode == bench::WALK && uint32_t(now - lastStep) >= 150) {
    lastStep = now;
    if (++walkChannel >= bench::CHANNELS) { stopOutputs(); return; }
    frame.clear(); frame.channel(walkChannel); sendFrame(); showStatic();
  }
  if (mode == bench::PULSE && uint32_t(micros() - lastPulse) >= 2000) {
    lastPulse = micros();
    // Marker goes HIGH in the same port write that makes OE LOW.
    // Measured pulse duration includes a small code overhead; verify on scope.
    noInterrupts();
    PORTB = (PORTB & ~_BV(PB1)) | _BV(PB0);
    delayMicroseconds(pulseWidth);
    PORTB = (PORTB | _BV(PB1)) & ~_BV(PB0);
    interrupts();
  }
}

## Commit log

2026-09-09 Launch Smart Spinner project site
    [ticker_spinner_v0_1_assembly.step, ticker_spinner_v0_1_bottom.step, ticker_spinner_v0_1_bottom.stl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]
2026-09-18 Add four-arm Ticker Spinner v0.3 package
    [ticker_spinner_v0_3_assembly.step, ticker_spinner_v0_3_bottom.step, ticker_spinner_v0_3_bottom.stl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]
2026-09-21 Update project site to four-arm v0.3
2026-09-21 Replace drawings with four-arm v0.3 sheets
2026-09-21 Update README for four-arm v0.3
2026-09-21 Add SmartSpinner v0.4 electronics core files
    [smartspinner_main_v0_4.kicad_pcb, smartspinner_tip_v0_4.kicad_pcb, smartspinner_v0_4_bom.csv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]
2026-09-21 Add SmartSpinner v0.4 assembly position files
    [smartspinner_main_v0_4_cpl.csv, smartspinner_tip_v0_4_cpl.csv]
2026-09-21 Prepare SmartSpinner v0.4 supplier RFQ package
    [02_SUPPLIER_RESPONSE_TEMPLATE.csv]
2026-09-22 Add SmartSpinner v0.5 principle schematic and RFQ package
    [smartspinner_main_v0_4-B_Cu.gbl, smartspinner_main_v0_4-B_Fab.gbr, smartspinner_main_v0_4-Edge_Cuts.gm1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]
2026-09-30 Publish B0.1 bench documentation and reference photos; retire obsolete packages
    [smartspinner_main_v0_4-B_Cu.gbl, smartspinner_main_v0_4-B_Fab.gbr, smartspinner_main_v0_4-Edge_Cuts.gm1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]
